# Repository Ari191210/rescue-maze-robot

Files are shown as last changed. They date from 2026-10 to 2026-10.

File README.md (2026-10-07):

# Rescue Maze Robot

Arduino Nano, dual RMCS-2303 Modbus drives, encoder dead reckoning. Firmware iterated through ~15 versions, built for RoboCup Junior-style Rescue Maze competition.

## What it does

The robot runs a hardcoded sequence of moves (forward / turn left / turn right / u-turn) through a maze, one cell at a time, using wheel-encoder counts to measure distance and turn angle rather than external walls or vision. Route is set as a string (e.g. `"FFRFLF"`) and edited directly in firmware before each run.

Earlier builds (same codebase, documented in [CHANGELOG.md](CHANGELOG.md)) used wall-following with PID correction against four I2C distance sensors (front/right/back/left). The current build removes that and drives purely on calibrated dead reckoning.

## How it works

```mermaid
flowchart TD
    Nano[Arduino Nano] -->|SoftwareSerial, Modbus-style| LeftDrive[RMCS-2303 drive — left wheel]
    Nano -->|SoftwareSerial, Modbus-style| RightDrive[RMCS-2303 drive — right wheel]
    Nano -->|I2C, addresses 0x08-0x0B| DistSensors[4x I2C distance sensors<br/>front / right / back / left]
    LeftDrive --> WheelL[Left wheel + encoder]
    RightDrive --> WheelR[Right wheel + encoder]
    Nano -->|EEPROM| Config[Stored tuning constants]
    Nano -->|Serial| Operator[Serial monitor: reset cause, diagnostics]
```

- A single Arduino Nano is the only onboard compute — no Raspberry Pi, no external vision in this build.
- Two RMCS-2303 drives talk to the Nano over `SoftwareSerial`, one per wheel, each with its own slave ID.
- Encoder counts per cell and per 90° turn are hand-calibrated constants (`COUNTS_PER_CELL`, `COUNTS_PER_90`) rather than measured live.
- A watchdog timer and AVR brownout/reset-cause capture run at boot to catch power-supply sag under motor load, a recurring failure mode during development (see CHANGELOG).

## Hardware / Stack

- Arduino Nano (ATmega328-based — uses `avr/wdt.h`)
- 2x RMCS-2303 Modbus motor drives (via `RMCS2303drive` library, `SoftwareSerial` on D2/D3)
- 4x I2C distance sensors at addresses `0x08`–`0x0B` (front/right/back/left), present in firmware but unused for movement in the current hardcoded-path mode
- Wheel encoders for dead-reckoning distance/turn measurement
- Custom-designed chassis (`hardware/maze_chassis.step`, `.stl`)

## Setup & Run

1. Open `firmware/maze_v15_pure_hardcode.ino` in the Arduino IDE.
2. Install the `RMCS2303drive` library (and its dependencies) via Library Manager.
3. Wire: RMCS-2303 drives on `SoftwareSerial(2, 3)`, left drive ID `7`, right drive ID `3`. I2C sensors on `Wire` (0x08–0x0B) if populated.
4. Calibrate before any real run:
   - `TEST_MODE = 6`: combined motor/encoder diagnostic — confirms both wheels respond and reports encoder deltas.
   - `TEST_MODE = 2`: turn calibration — tune `STOP_MARGIN_TURN` until a commanded 90° turn is a real 90°.
   - `TEST_MODE = 7`: sensor test (motors off) — read raw I2C distance values if sensors are attached.
5. Set `COUNTS_PER_CELL` to match your actual cell size (default assumes one forward move `F` = 300mm).
6. Edit `PATH[]` to the maze route, as seen from the robot's start orientation.
7. Set `TEST_MODE = 8` and upload — the robot runs `PATH[]` in order.

## Results & Limitations

- Pure dead-reckoning drive: there is no live correction against walls, so accuracy depends entirely on correct calibration of `COUNTS_PER_CELL` and `STOP_MARGIN_TURN`, and on consistent power delivery (brownouts were a recurring failure during development — see CHANGELOG).

## What's next

- A planned upgrade adds a Raspberry Pi 5, RPLIDAR, BNO055 IMU, and a YOLOv8n vision pipeline on a Hailo-8L accelerator for autonomous (non-hardcoded) navigation. That work has not been built or committed yet — this repo currently reflects the Nano-only hardcoded-path build.

## Hardware files

`hardware/maze_chassis.step` and `hardware/maze_chassis.stl` — chassis CAD.

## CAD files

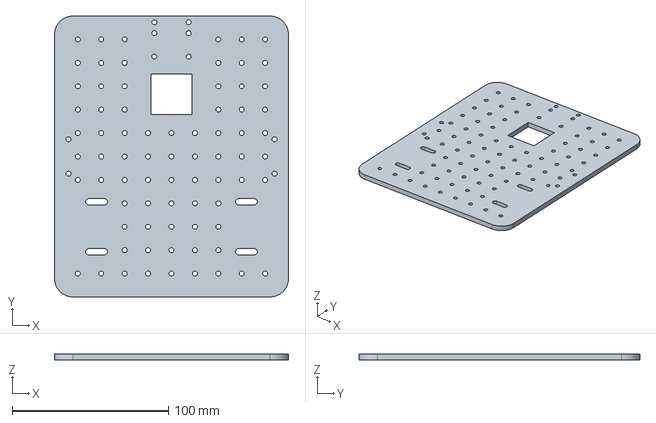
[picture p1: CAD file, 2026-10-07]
hardware/maze_chassis.step
150.0 x 180.0 x 4.00 mm

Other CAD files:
hardware/maze_chassis.stl

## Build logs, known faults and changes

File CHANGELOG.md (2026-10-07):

# Changelog

No git history exists for this project — it was developed as a series of numbered `.ino` files. This changelog is reconstructed from the version history documented inline in the firmware's own header comments, plus file timestamps. Entries before v13 are summarized from those comments only; intermediate files (v10–v12) exist on disk but their individual diffs weren't separately documented, so they're grouped here rather than itemized.

## v15 — 2026-07-07 (current build, `firmware/maze_v15_pure_hardcode.ino`)
"100% pure hardcode" — removed wall-following and PID correction entirely. Drive is now pure encoder-count dead reckoning against a hardcoded `PATH[]` string. Everything depends on `COUNTS_PER_CELL`, `STOP_MARGIN_TURN`, and `PATH[]` being calibrated correctly, since nothing corrects drift anymore.

## v14 — 2026-07-06/07
Added synchronized braking (both wheels brake together, fixing a 45° swing at each stop) and speed tapering (crawl the last `SLOW_ZONE` encoder counts before stopping, instead of slamming to a stop).

## v13 — 2026-07-07
Added `TEST_MODE=8`, a hardcoded-path mode where the route is typed as a string and run in order, while still using the wall-following PID drive underneath to self-correct against walls. Also: hardened encoder reads (reject 0-sentinel and glitch jumps), brownout detector at boot, corrected I2C sensor address→side mapping, and motion timeouts so a bad sensor read can't run the robot forever.

## v10–v12 — 2026-07-06
Diagnostic and stabilization pass on top of the wall-following PID build: brownout detector added, `TEST_MODE=6` combined motor/encoder diagnostic added, hardened encoder reads against sentinel/glitch values that were causing circling and bad cell-distance stops.

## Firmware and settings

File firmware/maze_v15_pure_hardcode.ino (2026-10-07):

// ==================================================================
//  RESCUE MAZE — COMPETITION BUILD v15 (100% PURE HARDCODE)
//  No sensors used for movement. No PID. No wall-following. The bot does
//  ONLY what PATH[] says, using encoder-count dead reckoning. This means
//  nothing corrects drift, so these THREE numbers MUST be right:
//     1) COUNTS_PER_CELL  -> one F = 300mm  (measure, then scale)
//     2) STOP_MARGIN_TURN -> a real 90 deg  (TEST_MODE=2 x3, average)
//     3) PATH[]           -> your route from START (bot's own view)
//  ---- history below ----
//  RESCUE MAZE — COMPETITION BUILD v14 (HARDCODE + clean stop)
//  v14: brake BOTH wheels together (kills the 45-deg swing at each stop)
//       + speed taper: crawl the last SLOW_ZONE counts so it eases into
//       the stop instead of slamming (kills overshoot + straightens stop).
//  ---- original v13 header below ----
//  RESCUE MAZE — COMPETITION BUILD v13 (HARDCODE MODE)
//  Nano #5 master: I2C sensors + RMCS-2303 x2 shared bus
//
//  v13: adds TEST_MODE=8 HARDCODED PATH. You type the route as a string
//  in PATH[] below; the bot runs those moves in order, still using the
//  wall-following PID drive so it self-corrects against walls instead of
//  drifting like raw timed moves would. All prior fixes kept:
//   - hardened encoder reads (rejects 0-sentinel + wild glitches)
//   - brownout detector at boot
//   - corrected sensor address->side mapping
//   - motion timeouts so a bad read can't run the bot forever
//
//  DIRECTION IS CONFIRMED CORRECT (Option A). Do NOT flip it.
// ==================================================================
#include <Wire.h>
#include <EEPROM.h>
#include <SoftwareSerial.h>
#include <RMCS2303drive.h>
#include <avr/wdt.h>

// ---- Reset-cause capture (runs before main(); AVR canonical method) ----
uint8_t mcusr_mirror __attribute__((section(".noinit")));
void grabResetCause(void) __attribute__((naked, used, section(".init3")));
void grabResetCause(void) {
  mcusr_mirror = MCUSR;
  MCUSR = 0;
  wdt_disable();
}

RMCS2303 rmcs;
SoftwareSerial rmcsSerial(2, 3);     // RX=D2, TX=D3

const byte LEFT_ID  = 7;   // verified: slave 7 = physical left
const byte RIGHT_ID = 3;   // verified: slave 3 = physical right

// ===== DIRECTION — CONFIRMED CORRECT (Option A). Do NOT change. =====
const byte LEFT_FWD  = 0;
const byte LEFT_REV  = 1;
const byte RIGHT_FWD = 1;
const byte RIGHT_REV = 0;

// ==================================================================
//  *** YOUR MAZE ROUTE — THIS IS THE MAIN THING YOU EDIT ***
//  Each letter = ONE action, run in order:
//     F = drive forward one cell
//     R = turn right 90 (in place, does NOT move forward)
//     L = turn left  90 (in place, does NOT move forward)
//     U = u-turn 180   (in place)
//  To round a right corner you write "RF": turn right, THEN go forward.
//  Example below = fwd, fwd, turn right, fwd, turn left, fwd:
const char PATH[] = "FFRFLF";     // <-- REPLACE with your actual route
// ==================================================================

const int INP_CONTROL_MODE = 257;
const int PP_gain = 10, PI_gain = 8, VF_gain = 32;
const int LPR = 334;
const int acceleration = 500;
const byte CONFIG_VERSION = 1;
const int  EEPROM_ADDR    = 0;

const int  BASE_SPEED      = 3000;
const int  TURN_SPEED      = 2000;
const int  DIAG_SPEED      = 1500;
const int  CRAWL_SPEED     = 1200;   // ease-in speed near the stop (taper)
const long SLOW_ZONE       = 1200;   // start crawling this many counts before brake point
const long COUNTS_PER_CELL = 4500;
const long COUNTS_PER_90   = 1695;

long STOP_MARGIN_CELL = 300;
long STOP_MARGIN_TURN = 400;   // PLACEHOLDER — CALIBRATE via TEST_MODE=2 (see notes)

const float KP = 3.0;
const float KD = 1.0;
const int   PID_CLAMP  = 300;
const int   ERR_CLAMP  = 60;
const int   WALL_NEAR  = 25;
const int   FRONT_STOP = 8;
const long  FB_MAX_JUMP = 15000;

// Address -> physical side, per verified cover-test:
//   0x09 = FRONT, 0x0A = RIGHT, 0x08 = BACK, 0x0B = LEFT
const uint8_t ADDR_F = 0x09, ADDR_R = 0x0A, ADDR_B = 0x08, ADDR_L = 0x0B;

// ---------------- Reset cause / brownout report ----------------
void printResetCause() {
  Serial.print(F("Reset cause: "));
  if (mcusr_mirror & (1 << PORF))  Serial.print(F("POWER-ON "));
  if (mcusr_mirror & (1 << EXTRF)) Serial.print(F("EXTERNAL(reset btn/upload) "));
  if (mcusr_mirror & (1 << BORF))  Serial.print(F("*** BROWNOUT *** "));
  if (mcusr_mirror & (1 << WDRF))  Serial.print(F("WATCHDOG "));
  if (mcusr_mirror == 0)           Serial.print(F("(cleared/unknown)"));
  Serial.println();
  if (mcusr_mirror & (1 << BORF)) {
    Serial.println(F(">> BROWNOUT: supply sagged. Fix power before trusting a run."));
  }
}

// ---------------- Sensors ----------------
int16_t readSensorOnce(uint8_t addr) {
  if (Wire.requestFrom(addr, (uint8_t)2) == 2) {
    int16_t v = (int16_t)((Wire.read() << 8) | Wire.read());  // HIGH byte first
    if (v > 0 && v < 500) return v;
  }
  return -1;
}

int16_t readDistance(uint8_t addr) {  // median of 3
  int16_t a = readSensorOnce(addr), b = readSensorOnce(addr), c = readSensorOnce(addr);
  if (a > b) { int16_t t = a; a = b; b = t; }
  if (b > c) { int16_t t = b; b = c; c = t; }
  if (a > b) { int16_t t = a; a = b; b = t; }
  return b;
}

bool wallNear(int16_t d) { return d > 0 && d < WALL_NEAR; }

// ---------------- Encoder feedback (with corrupt-read guard) ----------------
long lastGoodFB = 0;

long seedFB(byte id) {
  for (byte i = 0; i < 3; i++) {
    long fb = rmcs.Position_Feedback(id);
    if (fb != 0) { lastGoodFB = fb; return fb; }
    delay(5);
  }
  lastGoodFB = 0;
  return 0;
}

bool fbLooksBad(long fb) {
  if (fb == 0 && labs(lastGoodFB) > 3000) return true;      // sentinel
  if (labs(fb - lastGoodFB) > FB_MAX_JUMP) return true;      // wild glitch
  return false;
}

long safePosition(byte id) {
  long fb = rmcs.Position_Feedback(id);
  if (fbLooksBad(fb)) {
    long fb2 = rmcs.Position_Feedback(id);                   // one retry
    if (fbLooksBad(fb2)) return lastGoodFB;                  // hold last good
    fb = fb2;
  }
  lastGoodFB = fb;
  return fb;
}

// ---------------- Motor helpers ----------------
void stopMotors() {
  rmcs.Disable_Digital_Mode(LEFT_ID,  0);
  rmcs.Disable_Digital_Mode(RIGHT_ID, 0);
  delay(150);
}

void brakeStop(byte lDir, byte rDir) {
  rmcs.Brake_Motor(LEFT_ID,  lDir);
  rmcs.Brake_Motor(RIGHT_ID, rDir);   // BOTH together — no stagger -> no sideways kick
  delay(250);
  stopMotors();
}

void setSpeeds(int l, int r) {
  rmcs.Speed(LEFT_ID,  l);
  rmcs.Speed(RIGHT_ID, r);
}

void reportOvershoot(const __FlashStringHelper* tag, long startPos, long target) {
  delay(200);
  long endPos = safePosition(LEFT_ID);
  long final_d = labs(endPos - startPos);
  Serial.print(tag);
  Serial.print(F(" target=")); Serial.print(target);
  Serial.print(F(" final="));  Serial.print(final_d);
  Serial.print(F(" overshoot=")); Serial.println(final_d - target);
}

// ---------------- Drive one cell (wall-follow PID) ----------------
void driveOneCellPID() {
  long startPos = seedFB(LEFT_ID);
  long stopAt = COUNTS_PER_CELL - STOP_MARGIN_CELL;
  float lastError = 0;
  int lastL = BASE_SPEED, lastR = BASE_SPEED;
  uint8_t tick = 0;

  int16_t r0L = readDistance(ADDR_L);
  int16_t r0R = readDistance(ADDR_R);
  int16_t refL = wallNear(r0L) ? r0L : -1;
  int16_t refR = wallNear(r0R) ? r0R : -1;
  Serial.print(F("[CELL start] refL=")); Serial.print(refL);
  Serial.print(F(" refR="));             Serial.println(refR);

  setSpeeds(BASE_SPEED, BASE_SPEED);
  rmcs.Enable_Digital_Mode(LEFT_ID,  LEFT_FWD);
  delay(5);
  rmcs.Enable_Digital_Mode(RIGHT_ID, RIGHT_FWD);

  unsigned long cellStart = millis();
  while (true) {
    long delta = labs(safePosition(LEFT_ID) - startPos);
    if (delta >= stopAt) break;
    if (millis() - cellStart > 5000) { Serial.println(F("[CELL] TIMEOUT")); break; }

    int16_t dF = readDistance(ADDR_F);
    int16_t dL = readDistance(ADDR_L);
    int16_t dR = readDistance(ADDR_R);
    if (dF > 0 && dF < FRONT_STOP) { Serial.println(F("[CELL] front backstop")); break; }

    bool nearL = wallNear(dL);
    bool nearR = wallNear(dR);
    if (nearL && refL < 0) refL = dL;
    if (nearR && refR < 0) refR = dR;

    float error = 0;
    if (nearL && nearR)      error = (float)dL - (float)dR;
    else if (nearL)          error = (float)dL - (float)refL;
    else if (nearR)          error = (float)refR - (float)dR;

    error = constrain(error, -ERR_CLAMP, ERR_CLAMP);

    float pid = KP * error + KD * (error - lastError);
    lastError = error;
    pid = constrain(pid, -PID_CLAMP, PID_CLAMP);

    int cap = BASE_SPEED;
    if ((stopAt - delta) < SLOW_ZONE) cap = CRAWL_SPEED;   // ease into the stop
    int l = constrain(BASE_SPEED - (int)pid, 500, cap);
    int r = constrain(BASE_SPEED + (int)pid, 500, cap);

    if (abs(l - lastL) > 50) { rmcs.Speed(LEFT_ID,  l); lastL = l; }
    if (abs(r - lastR) > 50) { rmcs.Speed(RIGHT_ID, r); lastR = r; }

    if (++tick >= 5) {
      tick = 0;
      Serial.print(F("d="));   Serial.print(delta);
      Serial.print(F(" F="));  Serial.print(dF);
      Serial.print(F(" L="));  Serial.print(dL);
      Serial.print(F(" R="));  Serial.print(dR);
      Serial.print(F(" e="));  Serial.print(error, 0);
      Serial.print(F(" | "));  Serial.print(lastL);
      Serial.print(F("/"));    Serial.println(lastR);
    }
  }
  brakeStop(LEFT_FWD, RIGHT_FWD);
  reportOvershoot(F("[CELL]"), startPos, COUNTS_PER_CELL);
}

// ---------------- Turn ----------------
void turn90(int dir) {   // +1 right, -1 left
  long startPos = seedFB(LEFT_ID);
  long stopAt = COUNTS_PER_90 - STOP_MARGIN_TURN;
  byte lDir = (dir > 0) ? LEFT_FWD : LEFT_REV;
  byte rDir = (dir > 0) ? RIGHT_REV : RIGHT_FWD;

  Serial.print(F("[TURN] dir=")); Serial.println(dir > 0 ? F("RIGHT") : F("LEFT"));
  setSpeeds(TURN_SPEED, TURN_SPEED);
  rmcs.Enable_Digital_Mode(LEFT_ID,  lDir);
  delay(5);
  rmcs.Enable_Digital_Mode(RIGHT_ID, rDir);

  unsigned long turnStart = millis();
  while (labs(safePosition(LEFT_ID) - startPos) < stopAt) {
    if (millis() - turnStart > 3000) { Serial.println(F("[TURN] TIMEOUT")); break; }
  }
  brakeStop(lDir, rDir);
  reportOvershoot(F("[TURN]"), startPos, COUNTS_PER_90);
}

void uTurn() { turn90(1); turn90(1); }

// ---- PURE dead-reckoning forward: NO sensors, NO PID, encoder count only ----
void driveForwardBlind() {
  long startPos = seedFB(LEFT_ID);
  long stopAt = COUNTS_PER_CELL - STOP_MARGIN_CELL;
  bool crawling = false;

  setSpeeds(BASE_SPEED, BASE_SPEED);
  rmcs.Enable_Digital_Mode(LEFT_ID,  LEFT_FWD);
  delay(5);
  rmcs.Enable_Digital_Mode(RIGHT_ID, RIGHT_FWD);

  unsigned long t0 = millis();
  while (true) {
    long delta = labs(safePosition(LEFT_ID) - startPos);
    if (delta >= stopAt) break;
    if (!crawling && (stopAt - delta) < SLOW_ZONE) {
      setSpeeds(CRAWL_SPEED, CRAWL_SPEED);   // ease into the stop, once
      crawling = true;
    }
    if (millis() - t0 > 5000) { Serial.println(F("[FWD] TIMEOUT")); break; }
  }
  brakeStop(LEFT_FWD, RIGHT_FWD);
  reportOvershoot(F("[FWD]"), startPos, COUNTS_PER_CELL);
}

// ---------------- HARDCODED PATH RUNNER (TEST_MODE=8) ----------------
void runHardcodedPath() {
  Serial.print(F("Hardcoded route: ")); Serial.println(PATH);
  Serial.println(F("Place bot at START. Running in 3s..."));
  delay(3000);

  for (byte i = 0; PATH[i] != '\0'; i++) {
    char cmd = PATH[i];
    Serial.print(F(">> step ")); Serial.print(i);
    Serial.print(F(" = "));      Serial.println(cmd);

    switch (cmd) {
      case 'F': driveForwardBlind(); break;   // PURE dead reckoning, no sensors
      case 'R': turn90(1);           break;   // right 90 in place
      case 'L': turn90(-1);          break;   // left 90 in place
      case 'U': uTurn();             break;   // u-turn 180
      default:
        Serial.print(F("   unknown cmd '")); Serial.print(cmd);
        Serial.println(F("' - skipped"));
        break;
    }
    delay(200);   // brief settle between actions
  }
  Serial.println(F("=== PATH COMPLETE ==="));
}

// ---------------- Auto maze step (kept as fallback, TEST_MODE=0) ----------------
void navigateStep() {
  int16_t dF = readDistance(ADDR_F);
  int16_t dR = readDistance(ADDR_R);
  int16_t dL = readDistance(ADDR_L);

  Serial.print(F("NAV F:")); Serial.print(dF);
  Serial.print(F(" R:"));    Serial.print(dR);
  Serial.print(F(" L:"));    Serial.println(dL);

  if      (!wallNear(dF)) { Serial.println(F("-> fwd"));   driveOneCellPID(); }
  else if (!wallNear(dR)) { Serial.println(F("-> right")); turn90(1);  driveOneCellPID(); }
  else if (!wallNear(dL)) { Serial.println(F("-> left"));  turn90(-1); driveOneCellPID(); }
  else                    { Serial.println(F("-> uturn")); uTurn(); }
}

// ---------------- Diagnostics ----------------
void spinOne(byte id, const __FlashStringHelper* label) {
  Serial.print(F("\n[SOLO] ")); Serial.println(label);
  long s = rmcs.Position_Feedback(id);
  rmcs.Speed(id, DIAG_SPEED);
  rmcs.Enable_Digital_Mode(id, 1);
  delay(2000);
  rmcs.Disable_Digital_Mode(id, 1);
  delay(300);
  long d = rmcs.Position_Feedback(id) - s;
  Serial.print(F("  delta=")); Serial.print(d);
  if (labs(d) < 200) Serial.println(F("   <-- WEAK/DEAD even alone"));
  else               Serial.println(F("   (ok, motor turns alone)"));
  delay(800);
}

void runSoloDiag() {
  Serial.println(F("\n===== SOLO DIAGNOSTIC (bot on blocks) ====="));
  spinOne(LEFT_ID,  F("[1] LEFT_ID(7) - expect PHYSICAL LEFT wheel"));
  spinOne(RIGHT_ID, F("[2] RIGHT_ID(3) - expect PHYSICAL RIGHT wheel"));
  Serial.println(F("===== SOLO DIAG DONE ====="));
}

void runSensorTest() {   // TEST_MODE=7, motors OFF
  int16_t f = readDistance(ADDR_F);
  int16_t r = readDistance(ADDR_R);
  int16_t b = readDistance(ADDR_B);
  int16_t l = readDistance(ADDR_L);
  Serial.print(F("F(0x09)=")); Serial.print(f);
  Serial.print(F("   R(0x0A)=")); Serial.print(r);
  Serial.print(F("   B(0x08)=")); Serial.print(b);
  Serial.print(F("   L(0x0B)=")); Serial.print(l);
  Serial.print(F("   [F")); Serial.print(wallNear(f) ? '#' : '.');
  Serial.print(F(" R")); Serial.print(wallNear(r) ? '#' : '.');
  Serial.print(F(" L")); Serial.print(wallNear(l) ? '#' : '.');
  Serial.println(F("]"));
  delay(300);
}

void configureDrivesIfNeeded() {
  if (EEPROM.read(EEPROM_ADDR) == CONFIG_VERSION) {
    Serial.println(F("Drive config: already written (skipping)."));
    return;
  }
  Serial.println(F("First boot: writing drive params..."));
  rmcs.WRITE_PARAMETER(LEFT_ID,  INP_CONTROL_MODE, PP_gain, PI_gain, VF_gain, LPR, acceleration, BASE_SPEED);
  rmcs.SAVE(LEFT_ID);
  delay(500);
  rmcs.WRITE_PARAMETER(RIGHT_ID, INP_CONTROL_MODE, PP_gain, PI_gain, VF_gain, LPR, acceleration, BASE_SPEED);
  rmcs.SAVE(RIGHT_ID);
  delay(500);
  EEPROM.write(EEPROM_ADDR, CONFIG_VERSION);
  Serial.println(F("Drive config saved."));
}

// 0 = auto maze | 1 = one cell | 2 = right turn | 3 = left turn
// 4 = square | 5 = solo diag | 7 = sensor test | 8 = HARDCODED PATH
const byte TEST_MODE = 8;   // <-- 8 runs your PATH[] route
bool done = false;

void setup() {
  rmcs.Serial_selection(1);
  rmcs.Serial0(9600);
  rmcs.begin(&rmcsSerial, 9600);

  stopMotors();

  Serial.begin(9600);
  delay(50);
  Serial.println(F("\n\n=== MAZE v13 boot ==="));
  printResetCause();
  configureDrivesIfNeeded();

  Wire.begin();
  Serial.print(F("TEST_MODE=")); Serial.print(TEST_MODE);
  Serial.print(F("  BASE=")); Serial.print(BASE_SPEED);
  Serial.print(F("  TURN_MARGIN=")); Serial.println(STOP_MARGIN_TURN);
  Serial.println(F("Ready.\n"));
  delay(1500);
}

void loop() {
  if (done) return;
  switch (TEST_MODE) {
    case 0: navigateStep(); delay(300); return;
    case 1: driveOneCellPID(); break;
    case 2: turn90(1); break;
    case 3: turn90(-1); break;
    case 4: for (byte i = 0; i < 4; i++) { driveOneCellPID(); turn90(1); } break;
    case 5: runSoloDiag(); break;
    case 7: runSensorTest(); return;
    case 8: runHardcodedPath(); break;   // <-- your hardcoded route
  }
  done = true;
}
